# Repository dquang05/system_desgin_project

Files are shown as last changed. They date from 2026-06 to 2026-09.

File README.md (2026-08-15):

# ESP32 Autonomous Mobile Robot (AMR)





An advanced Autonomous Mobile Robot firmware built on the **ESP-IDF v5.x** framework. Designed with strict real-time constraints, thread-safety, and modular architecture, this project demonstrates professional-grade embedded systems engineering using **FreeRTOS** and Object-Oriented C++.

## 🚀 System Architecture

The firmware is designed with a strict **Application-Library Separation**.

- `lib/`: Contains hardware-agnostic, non-blocking drivers (Motor Control, PID, ADC DMA, Loadcell, Wi-Fi). No FreeRTOS tasks are spawned here.
- `src/`: The Application layer orchestrating high-level state machines, task creation, and global resource management.

### Key Engineering Highlights

- **Deterministic Real-Time Execution:** Motion control and PID loops run precisely at 100Hz in a pinned Core 1 task.
- **Thread Safety:** Lock-free passing where possible, combined with strict `portENTER_CRITICAL` Spinlocks for sharing high-frequency data (like Encoder ticks and ADC raw values) across multicore tasks.
- **Zero Dynamic Allocation in Critical Loops:** No `malloc` or `new` in polling loops. Memory is strictly stack-allocated or statically provisioned at startup to prevent Heap Fragmentation.
- **Direct Memory Access (DMA):** The 5-channel Infrared Line Sensor array is sampled at 20kHz continuously via ESP32's ADC DMA hardware, entirely offloading the CPU.

## 🧠 Control Algorithms

### 1. Velocity Control (Low-Level)

- **Incremental PID Controller:** Controls the TB6612 H-Bridge drivers coupled with Quadrature Encoders.
- **Slew Rate Limiting:** Prevents sudden current spikes (Back-EMF) by artificially capping the maximum acceleration `dv/dt`.
- **Integral Anti-Windup:** Prevents overshooting when wheels are mechanically jammed or lose traction.

### 2. Autonomous Navigation (High-Level)

- **Line Tracking:** Uses Weighted Average (Centroid) calculation with Affine Calibration to determine precise offset error (`e2`).
- **State Machine:** Seamlessly transitions between `MOVING_TO_PICKUP`, `WAITING_FOR_PACKAGE` (Loadcell integration), and `DELIVERING`.
- **Two-Phase Pivot Turn:** Executes precise turning maneuvers at intersections without the need for IMU/Compass, relying purely on encoder odometry and side-sensor polling.

### 3. Remote Telemetry & Tuning

- Utilizes asynchronous **UDP Sockets** to broadcast telemetry data (RPM, Duty Cycle, Sensor Arrays) to a local network at high frequency.
- Supports Live-Tuning: Send a JSON payload via UDP to dynamically update PID gains, steering RPMs, or loadcell thresholds **without recompiling or halting the robot**.

## 🛠️ Build & Flash Instructions

This project is configured using standard ESP-IDF CMake.

1. **Prerequisites:** Ensure ESP-IDF v5.x is installed.
2. **Set Target:**
   ```bash
   idf.py set-target esp32
   ```
3. **Build & Flash:**
   ```bash
   idf.py build
   idf.py -p PORT flash monitor
   ```

## 📁 Repository Structure

```text
├── MCU/
│   ├── include/           # Shared structures, Configs, and Orchestrator Headers
│   ├── src/               # FreeRTOS Tasks (Motion, Telemetry, UDP) & Main
│   ├── lib/               # Independent Component Libraries
│   │   ├── adc_dma/       # Continuous DMA ADC Driver
│   │   ├── loadcell_hx711/# HX711 Weight Sensor
│   │   ├── tb6612_encoder/# Motor & Quadrature Encoder Driver
│   │   ├── velocity_pid/  # Slew-Rate Limited PID
│   │   └── wifi_manager/  # Wi-Fi Station & AP provisioning
│   └── CMakeLists.txt     # Global IDF Component Registration
└── UI/                    # Node.js Server & Web Dashboard for UDP Telemetry
```

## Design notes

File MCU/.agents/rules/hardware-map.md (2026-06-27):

---
trigger: model_decision
---

# ESP32-WROOM-32 Hardware Truth (uPesy DevKit)

## 1. RESERVED & HARDWARE-RESTRICTED GPIOs (ABSOLUTE LIMITS)

> **Never assign outputs or remap peripherals to the following GPIOs.**

| GPIO | Category | Hardware Restriction |
|---|---|---|
| **6, 7, 8, 9, 10, 11** | Internal SPI Flash | **DO NOT USE.** These pins are permanently connected to the onboard SPI Flash. Accessing them will cause an immediate Guru Meditation (Crash). |
| **34, 35, 36 (VP), 39 (VN)** | Input Only | **INPUT ONLY.** No output driver and no internal pull-up/pull-down resistors. Never use them for PWM, UART TX, SPI output, or any output function. |

---

## 2. STRAPPING PINS (BOOT CONFIGURATION)

> These GPIOs determine the ESP32 boot mode. External circuitry must never force them into an invalid state during power-up or reset.

| GPIO | Strapping Function | Hardware Constraint |
|---|---|---|
| **0** | Boot Mode | Must be **LOW** to enter download mode. Use caution when connecting buttons or external devices. |
| **2** | Boot Mode & Onboard LED | Must remain in a valid boot state during reset. Commonly connected to the onboard blue LED. |
| **5** | SDIO Timing | Must be **HIGH** during boot. Safe for SPI CS or PWM after boot completes. |
| **12** | Flash Voltage Selection | **CRITICAL.** Must be **LOW** during boot. Driving HIGH selects 1.8V Flash mode and prevents normal boot. |
| **15** | Boot Message Configuration | HIGH enables boot log output, LOW suppresses boot messages. |

---

## 3. DEFAULT PERIPHERAL PIN ASSIGNMENT

> Prefer these default IO-MUX pins unless the hardware design requires GPIO Matrix remapping.

| Peripheral | GPIO Assignment | Notes |
|---|---|---|
| **UART0 (Programming / System Log)** | TX = **1**, RX = **3** | Reserved for USB-UART programming and serial monitor. Avoid using for external peripherals. |
| **UART2** | TX = **17**, RX = **16** | Preferred hardware UART for GPS, LiDAR, and other external modules. |
| **I2C0** | SDA = **21**, SCL = **22** | Default I2C pins. Internal pull-up support available. |
| **VSPI** | MOSI = **23**, MISO = **19**, SCK = **18**, CS = **5** | Preferred SPI bus for maximum compatibility and performance. |

---

## 4. DYNAMIC GPIO MATRIX ALLOCATION

> These assignments depend on the actual hardware design. Always read this table before configuring firmware.

| Function | GPIO | Direction | Notes |
|---|---|---|---|
| **MOTOR_L_PWM** | `[Assign GPIO]` | Output | Use MCPWM or LEDC |
| **MOTOR_R_PWM** | `[Assign GPIO]` | Output | Use MCPWM or LEDC |
| **ENCODER_L_A** | `[Assign GPIO]` | Input | Use PCNT (Pulse Counter) |
| **ENCODER_L_B** | `[Assign GPIO]` | Input | Use PCNT (Pulse Counter) |
| **ENCODER_R_A** | `[Assign GPIO]` | Input | Use PCNT (Pulse Counter) |
| **ENCODER_R_B** | `[Assign GPIO]` | Input | Use PCNT (Pulse Counter) |

---

## 5. ANALOG INPUTS (FIXED ADC CHANNELS)

> Analog sensors must use dedicated ADC GPIOs. Prefer **ADC1** channels to avoid conflicts with Wi-Fi.

| Analog Sensor | GPIO | ADC Channel | Notes |
|---|---|---|---|
| `[Sensor Name]` | `[Assign GPIO]` | `ADC1_CHx` | Prefer ADC1 for Wi-Fi compatibility |

---

## 6. HIGH-SPEED DMA PERIPHERALS (FIXED IO-MUX)

> For high-speed SPI/I2S with DMA, use the native IO-MUX pins below. Do not remap these signals if maximum performance is required.

### VSPI (Up to 80 MHz with DMA)

| Signal | GPIO |
|---|---|
| SCK | **18** |
| MISO | **19** |
| MOSI | **23** |
| CS | **5** |

### HSPI (Up to 80 MHz with DMA)

| Signal | GPIO |
|---|---|
| SCK | **14** |
| MISO | **12** |
| MOSI | **13** |
| CS | **15** |

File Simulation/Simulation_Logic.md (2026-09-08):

# Tài liệu Mô tả Logic Mô phỏng Hệ thống Xe Tự hành (Line Tracking)

Hệ thống mô phỏng một xe tự hành bám đường (line tracking) dựa trên mô hình động học vi sai (differential drive). Quá trình điều khiển được chia làm hai vòng lặp lồng nhau (cascade control): vòng ngoài (Outer Loop) điều hướng xe để bám quỹ đạo dựa trên cảm biến mô phỏng; vòng trong (Inner Loop) điều khiển tốc độ thực tế của từng động cơ trái/phải thông qua các hàm truyền.

Dưới đây là mô tả chi tiết logic và luồng hoạt động của hệ thống, cùng với vai trò của từng file tham gia vào các bước:

## 1. Khởi tạo hệ thống và Sa bàn
**Script chính:** [`main.m`](file:///d:/Projects/system_desgin_project/Simulation/main.m)

- **Thông số cơ học:**
  - Khoảng cách giữa 2 bánh xe (Track width): `b = 246 mm`
  - Khoảng cách từ tâm mảng cảm biến (dò line) đến trục bánh xe: `d = 176 mm`
  - Bán kính bánh xe: `r = 40 mm`
- **Khởi tạo vị trí ban đầu:** 
  - Tâm xe ban đầu tại `(xM, yM) = (0, 0)`, góc lệch `phi = pi`.
  - Tọa độ tâm mảng cảm biến dò line: `xC, yC` được xác định theo tọa độ tâm xe và khoảng cách `d`.
- **Vẽ sa bàn:** Gọi script phụ trợ [`saban.m`](file:///d:/Projects/system_desgin_project/Simulation/saban.m) để phác họa bản đồ môi trường di chuyển với các điểm mốc và giới hạn tọa độ.

---

## 2. Vòng lặp Mô phỏng (Simulation Loop)
Quá trình chạy trong 200 bước (tần số lấy mẫu chung `tsampsys = 0.2s`, khoảng 40 giây thực thi). Tại mỗi chu kỳ, hệ thống thực hiện tuần tự:

### 2.1 Tính toán sai số bám line (Đọc cảm biến)
**Hàm thực thi:** [`get_e2.m`](file:///d:/Projects/system_desgin_project/Simulation/get_e2.m)

- Trạng thái đường đi của xe được chia thành **8 phân đoạn (lines)** dựa trên tọa độ di chuyển dọc trục `xC`.
- **Rẽ nhánh (Phân đoạn 1):** Khi `xC < -2000`, hàm gọi `questdlg` hiển thị popup để chọn lộ trình rẽ: **"Red" (Đỏ)** hoặc **"Blue" (Xanh)**. Biến `color` (1 hoặc 2) lưu trữ lựa chọn sẽ định tuyến cho các phương trình quỹ đạo ở phân đoạn 5, 6, 7 và 8.
- **Tính toán sai số lệch đường (`e`):** Hàm dùng phương trình hình học của đường (thẳng/cong) để chiếu tìm vị trí tâm đường lý tưởng `(xR, yR)`. Từ đó tính toán khoảng cách vuông góc `e` (bằng mm) đại diện cho độ lệch giữa mảng cảm biến xe và trung tâm vạch kẻ lý tưởng.

### 2.2 Bộ điều khiển hướng (Outer Loop PID)
**Hàm thực thi:** [`tracking_line.m`](file:///d:/Projects/system_desgin_project/Simulation/tracking_line.m)

- **Đầu vào:** Sai số vị trí `e` ở chu kỳ hiện tại.
- Bộ điều khiển sử dụng cấu trúc **PID vị trí** (ví dụ: `Kp = 0.045`, `Ki = 0.0`, `Kd = 0.001`) để tính ra tín hiệu điều khiển `w` - vận tốc góc bẻ lái để đưa xe về đúng quỹ đạo.
- Kết hợp với tốc độ chạy tới danh định `vR = 500 mm/s`, bộ điều khiển tổng hợp và trả về **vận tốc góc mục tiêu (RPM)** cho 2 bánh xe trái/phải (`wl`, `wr`).

### 2.3 Mô phỏng điều khiển động cơ (Inner Loop PID)
**Hàm thực thi:** [`pid_motor_left.m`](file:///d:/Projects/system_desgin_project/Simulation/pid_motor_left.m), [`pid_motor_right.m`](file:///d:/Projects/system_desgin_project/Simulation/pid_motor_right.m) và các hàm truyền như [`motor1_tf.m`](file:///d:/Projects/system_desgin_project/Simulation/motor1_tf.m).

Động cơ thực tế có quán tính và độ trễ, do đó phần này được lấy mẫu cao hơn (vòng lặp con với chu kỳ `tsamppid = 0.03s`).
- **PID Tốc độ:** Mỗi động cơ chạy bộ điều khiển PI riêng biệt (ví dụ: `kp1 = 1.0673`, `ki1 = 13.948`) nhằm điều chỉnh sai lệch giữa tốc độ đang chạy và tốc độ yêu cầu (`wl`, `wr`). Đầu ra của PID là giá trị băm xung PWM (`ul`, `ur` trong giới hạn 0-255).
- **Hàm truyền:** Cấp PWM vào hàm truyền bậc 1 của động cơ (`K = 12.05`, `a = 10.64`).
- Hệ thống giải phương trình vi phân liên tục qua lệnh `ode45` trong MATLAB để tìm ra **vận tốc tịnh tiến thực tế** `vl`, `vr` (mm/s) đáp ứng ra tại bánh xe.

### 2.4 Cập nhật động học hệ thống (Kinematics)
**Hàm thực thi:** [`dynamic_tf.m`](file:///d:/Projects/system_desgin_project/Simulation/dynamic_tf.m) tích hợp trong `main.m`.

- Từ vận tốc thực tế của hai bánh `vl`, `vr`, xác định vận tốc tịnh tiến hệ thống: $v_{input} = \frac{vl + vr}{2}$ và vận tốc xoay thân xe $w_{input} = \frac{vr - vl}{b}$.
- Đưa qua phương trình vi phân động học robot vi sai:
  - $\dot{x} = v \cos(\phi)$
  - $\dot{y} = v \sin(\phi)$
  - $\dot{\phi} = w$
- Giải qua `ode45` để tìm ra tọa độ không gian mới `(xM, yM)` và góc hướng mũi xe `phi`. Cập nhật tịnh tiến mảng cảm biến `(xC, yC)` lên phía trước.
- Xóa frame cũ và vẽ đè hình ảnh xe mới bằng các hàm `plot` và lệnh `drawnow`, sinh ra hoạt ảnh xe di chuyển mượt mà trên môi trường giả lập.

---

## 3. Phân tích Đáp ứng Động cơ (Hỗ trợ)
**Script phụ trợ:** [`motor_response.m`](file:///d:/Projects/system_desgin_project/Simulation/motor_response.m)

- Đóng vai trò là kịch bản mô phỏng tĩnh để đánh giá thiết kế vòng điều khiển vận tốc.
- Sinh đồ thị hàm Step (Step Response) cho vòng kín chứa Động cơ + Bộ PID vận tốc.
- Phân tích và trích xuất các chỉ số chất lượng: **Overshoot** (Độ vọt lố), **Settling Time** (Thời gian xác lập), và **Steady-State Error** (Sai số xác lập) lưu vào tập tin báo cáo `motor_simulation_results.txt`.

---

## 4. Tổng hợp Kết quả và Báo cáo (Kết thúc mô phỏng)
Sau 200 chu kỳ chạy, cuối file `main.m` thực hiện lưu vết và phân tích:
1. **Biểu đồ trực quan:**
   - Đồ thị sai số cảm biến dò line theo thời gian (quan sát độ lặp, lắc thân xe).
   - Đồ thị tốc độ góc mong muốn của 2 bánh xe (RPM).
   - Đồ thị tốc độ dài thực tế của động cơ sau xử lý độ trễ (mm/s).
2. **Xuất báo cáo văn bản:** Trích xuất kết quả ra tệp [`main_simulation_results.txt`](file:///d:/Projects/system_desgin_project/Simulation/main_simulation_results.txt) gồm:
   - Sai số hiệu dụng (RMS Error) và sai số tích phân (IAE).
   - Số lần cắt ngang tâm đường (Zero-crossings) cảnh báo xe bị lắc.
   - Vị trí và khoảng thời gian xe bị overshoot lệch khỏi quỹ đạo xa nhất.

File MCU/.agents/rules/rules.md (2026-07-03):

---
trigger: glob
globs: src/**/*.{c,cpp,h}, include/**/*.h, lib/**/*.{c,cpp,h}, **/CMakeLists.txt
---

Role: ESP32 Firmware Engineer (PlatformIO & ESP-IDF v5.4)

# Architecture & Build Rules

- Framework: ESP-IDF v5.4 ONLY (No Arduino). Structure: `src/`, `include/`, `lib/`.
- Build: Always update `CMakeLists.txt` (`idf_component_register`) when adding `.c/.cpp/.h/.hpp`. Never edit `sdkconfig` directly.
- API: Strictly use v5.x drivers (e.g., `mcpwm_prelude.h`). Zero v4.x legacy APIs.

# Coding Style & Library Design

- Naming: `snake_case` (files, methods, vars), `PascalCase` (classes), `UPPER_SNAKE_CASE` (macros). Private vars prefix: `_`.
- Decoupling [CRITICAL]: NO hardcoded pins/magic numbers in `lib/`. Pass via config structs, macros, or `constexpr` in headers.
- Task Architecture [CRITICAL]: NEVER create FreeRTOS tasks inside `lib/`. Libraries must expose non-blocking methods (`process()`, `poll()`). Task creation belongs strictly to the App layer (`main`).
- Syntax [CRITICAL]: C++17 or C++20.

# Memory & Resource Management

- Allocation: NO dynamic allocation (`malloc`, `new`, `std::vector`, `std::string`) in continuous loops or ISRs. Use static/stack memory (`std::array`, C-arrays). If required, allocate exactly once at `init()`. Prefer static FreeRTOS objects.
- Safety: Always bounds-check arrays, NULL-check pointers, race-condition check. Full cleanup on deinit (disable modules, reset GPIOs, free ISRs).

# Hardware, Clock & Peripherals

- Clocks: Use `esp_clk_apb_freq()` (Never hardcode 80MHz). Validate clock configs. Wrap all inits in `ESP_ERROR_CHECK()`. Always call `periph_module_enable()` before register access.
- SPI & GPIO: SPI FIFO > 64B MUST be chunked. Route pins via `gpio_matrix_out/in()`.
- Concurrency: Protect ISR/Task shared memory using spinlocks (`portENTER_CRITICAL`).

# FreeRTOS & Safety Checks

- Execution: Every polling loop MUST have a time-based timeout (`esp_timer_get_time()`). No infinite loops.
- WDT: DO NOT bypass WDT with `esp_task_wdt_reset()`; fix CPU starvation instead. Always yield CPU (`vTaskDelay`, `taskYIELD()`) in heavy loops.

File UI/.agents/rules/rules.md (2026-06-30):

---
trigger: always_on
---

# UI Project Agent Rules

## Tech Stack

- Backend: Node.js, Express.js, Socket.io, `dgram` (UDP server).
- Frontend: Vanilla HTML, CSS, JavaScript. No frontend frameworks.
- Backend receives UDP datagrams from the MCU and forwards them to the frontend via WebSockets.

## Backend

- Keep the UDP-to-WebSocket bridge architecture.
- Implement UDP socket self-recovery on errors using automatic restart (e.g., `setTimeout`).
- Clean up all sockets and timers on `SIGINT` and `SIGTERM`.

## Frontend

- Use only native DOM APIs.
- Batch high-frequency updates with `requestAnimationFrame` and `DocumentFragment`.
- Limit log elements with a FIFO queue (maximum 1000).
- Sanitize all incoming data before inserting it into the DOM.
- Preserve the dark theme using `--bg-color`, `--panel-bg`, and `--accent`.
- Provide real-time status indicators and controls (auto-scroll, clear logs).
- Automatically parse and syntax-highlight JSON payloads in logs.

```

```

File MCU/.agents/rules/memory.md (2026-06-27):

---
trigger: always_on
glob:
description:
---

# ESP32 ADC DMA & FreeRTOS Lessons Learned

- **ADC Calibration**: ESP32 (classic) only supports `Line Fitting` calibration (`adc_cali_create_scheme_line_fitting`). Using `Curve Fitting` will fail as it is disabled in `adc_cali_scheme.h` for this chip.
- **ESP-IDF v5 Spinlock Initialization**: Avoid using internal macros like `vPortCPUInitializeMutex` in modern ESP-IDF v5.x to initialize a Spinlock (`portMUX_TYPE`). Instead, initialize it directly using the macro `portMUX_INITIALIZER_UNLOCKED` (e.g., `portMUX_TYPE _spinlock = portMUX_INITIALIZER_UNLOCKED;`).
- **ADC DMA Zero Queue Architecture**: To minimize overhead and avoid FreeRTOS RingBuffer or xQueue complexities, parse the ADC continuous DMA buffer locally on the stack and safely copy the latest complete frame to a shared struct protected by a Spinlock (`portENTER_CRITICAL` / `portEXIT_CRITICAL`). This prevents race conditions with minimal latency.
- **ADC Continuous Read Timeout**: The `timeout_ms` parameter in `adc_continuous_read()` expects raw milliseconds, NOT FreeRTOS ticks. Passing `pdMS_TO_TICKS(10)` evaluates to ~1ms (or 0), causing an immediate timeout and potential Task Watchdog (TWDT) crash due to a tight spinning loop.
- **Task Watchdog & Yielding**: When an infinite loop task polls for data (e.g., getting `ESP_ERR_TIMEOUT`), it MUST explicitly yield the CPU (e.g., using `vTaskDelay(pdMS_TO_TICKS(10))`) to prevent TWDT CPU starvation.
- **PlatformIO ESP-IDF Component Registration**: Any custom library placed in the `lib/` directory MUST have a `CMakeLists.txt` file calling `idf_component_register()` to be compiled and have its include paths exported properly to the rest of the project.

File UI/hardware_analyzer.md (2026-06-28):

# Hardware Analysis

Dựa trên mã nguồn C/C++ trong thư mục `hardware_code/`, các thông số mạng được trích xuất như sau:

- **Protocol**: UDP (`SOCK_DGRAM`)
  - Tìm thấy tại `wifi_manager.cpp`, dòng 184: `int sock = socket(AF_INET, SOCK_DGRAM, IPPROTO_IP);`
- **Port**: `8080`
  - Tìm thấy tại `WifiTest.cpp`, dòng 59: `wifi.send_log_data("192.168.1.100", 8080, ...)`

Server backend sẽ được thiết lập để lắng nghe UDP Datagram trên cổng `8080`.

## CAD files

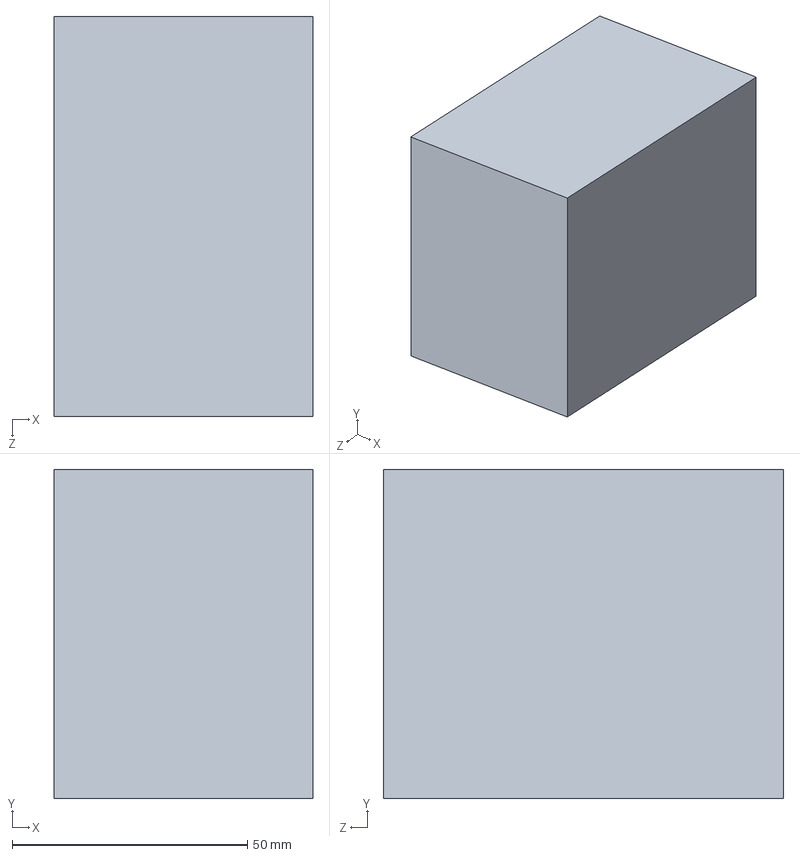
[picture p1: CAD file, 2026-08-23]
3D_Model/Tai_mau_do.SLDPRT
55.0 x 70.0 x 85.0 mm

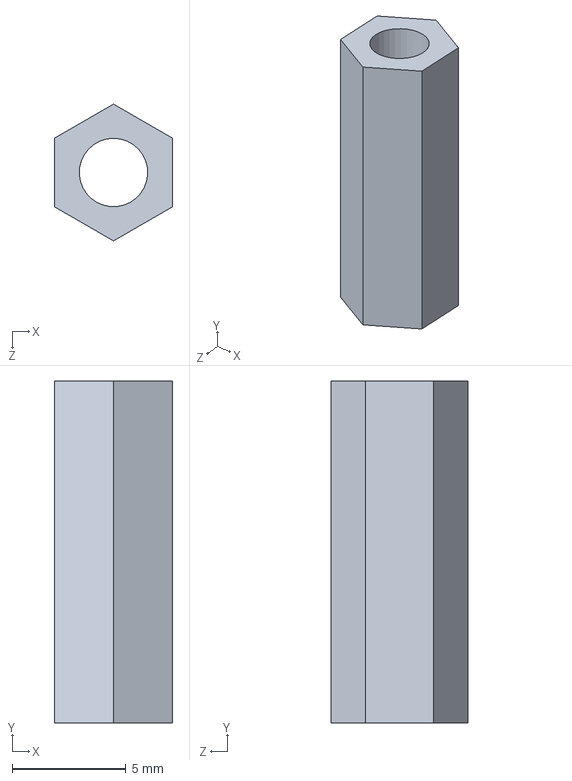
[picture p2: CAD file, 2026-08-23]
3D_Model/cot chong15.SLDPRT
5.20 x 15.0 x 6.00 mm

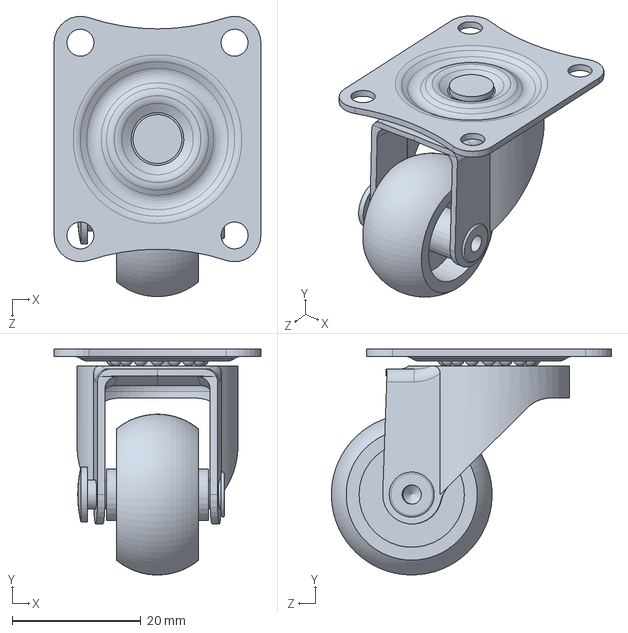
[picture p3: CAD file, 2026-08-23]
3D_Model/Caster_Wheel.SLDPRT
32.2 x 35.1 x 43.5 mm

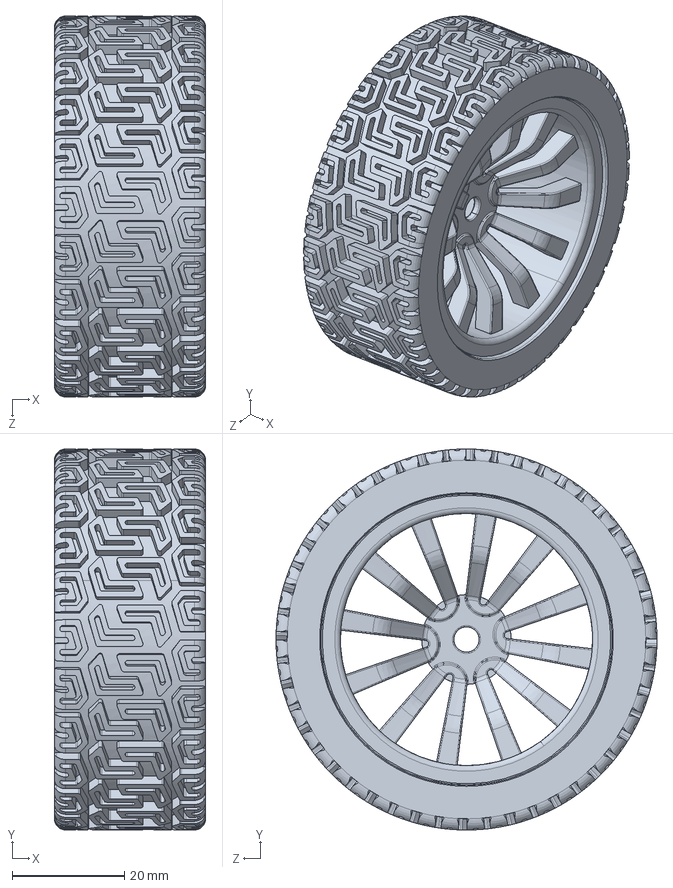
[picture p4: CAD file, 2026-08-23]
3D_Model/Banh_V2_65mm.SLDPRT
27.0 x 68.0 x 68.0 mm

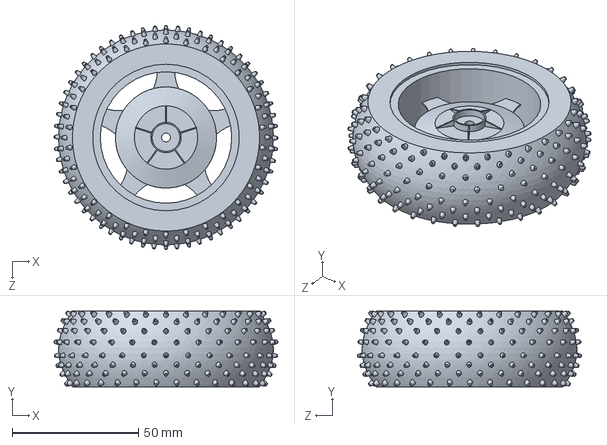
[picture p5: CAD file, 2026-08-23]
3D_Model/85mm_Wheel.SLDPRT
88.6 x 30.0 x 88.7 mm

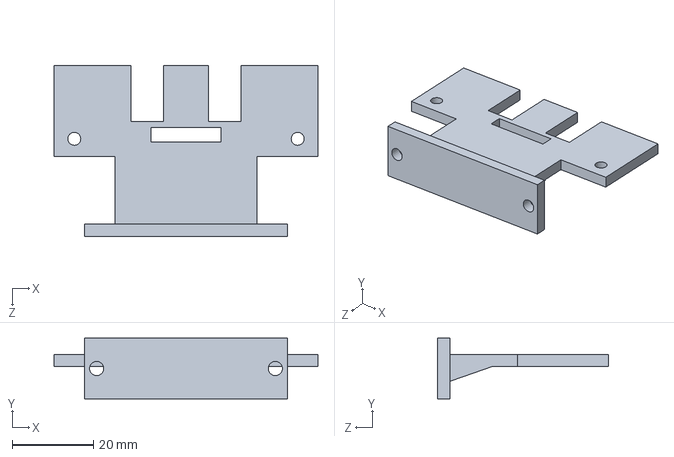
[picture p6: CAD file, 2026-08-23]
3D_Model/Ga_cam_bien_mau.SLDPRT
65.0 x 15.0 x 42.0 mm

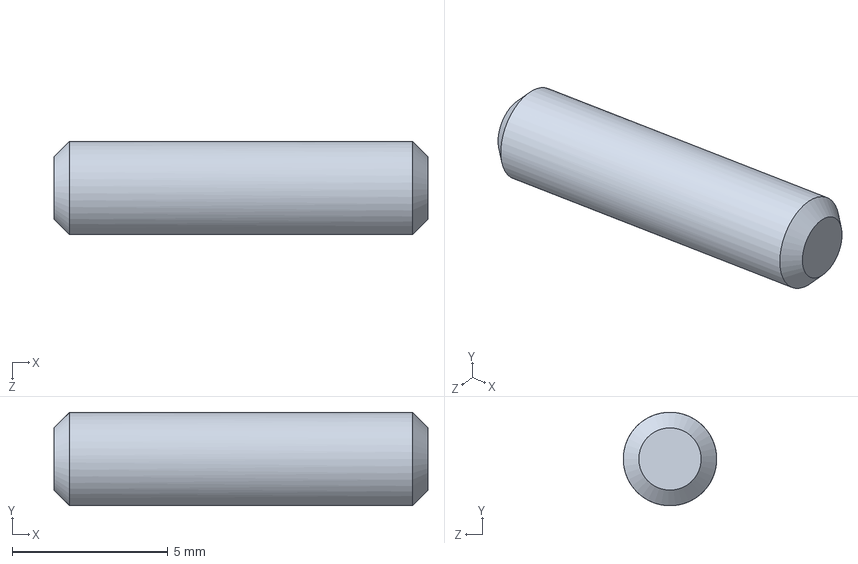
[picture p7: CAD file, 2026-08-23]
3D_Model/Chot_dinh_vi.SLDPRT
12.0 x 3.00 x 3.00 mm

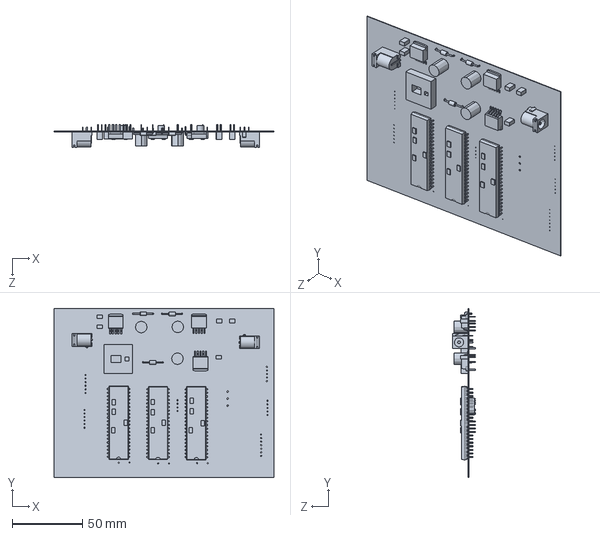
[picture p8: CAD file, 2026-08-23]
3D_Model/PCB.SLDPRT
156.6 x 120.5 x 16.0 mm

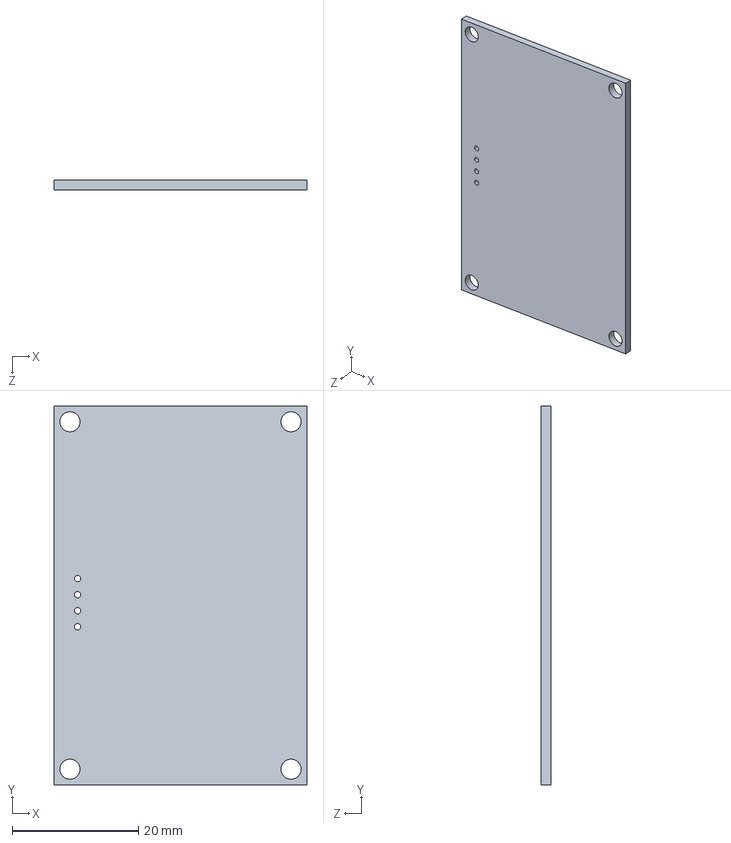
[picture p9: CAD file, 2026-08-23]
3D_Model/board_4x6.SLDPRT
40.0 x 60.0 x 1.51 mm

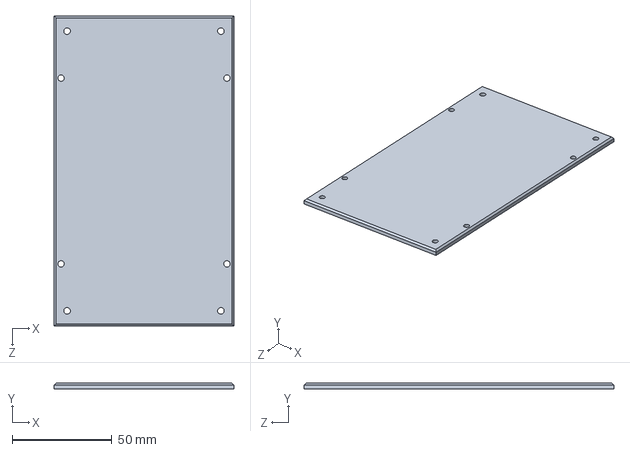
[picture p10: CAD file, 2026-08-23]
3D_Model/Part1.SLDPRT
90.0 x 3.00 x 155.2 mm

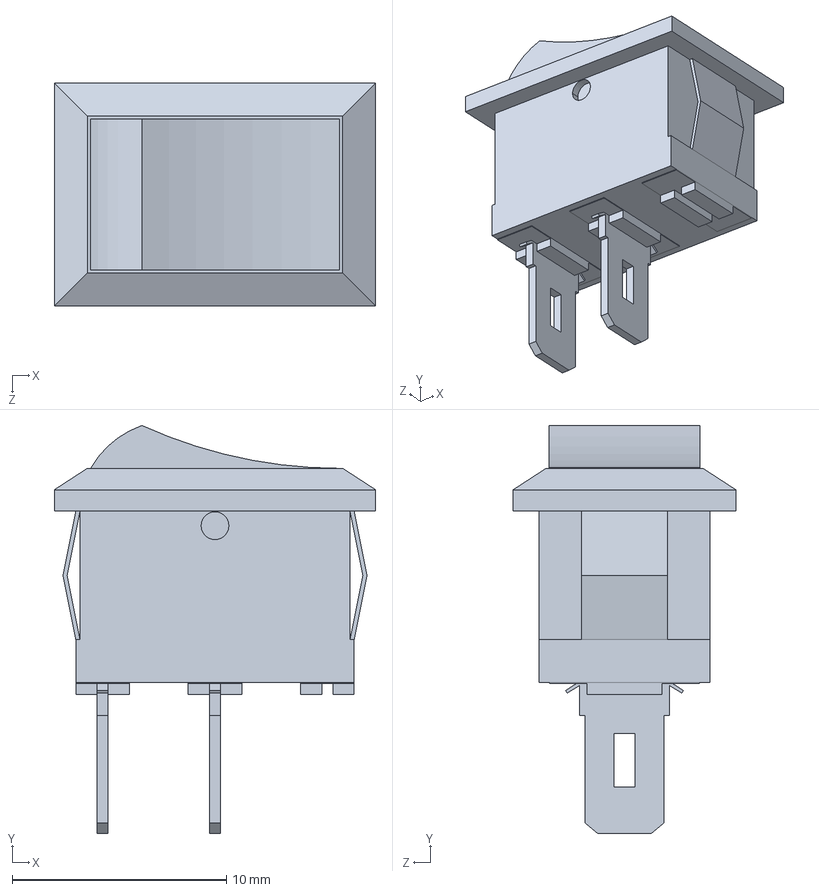
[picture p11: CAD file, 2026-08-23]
3D_Model/SwitchOnOff.SLDPRT
15.0 x 19.1 x 10.4 mm

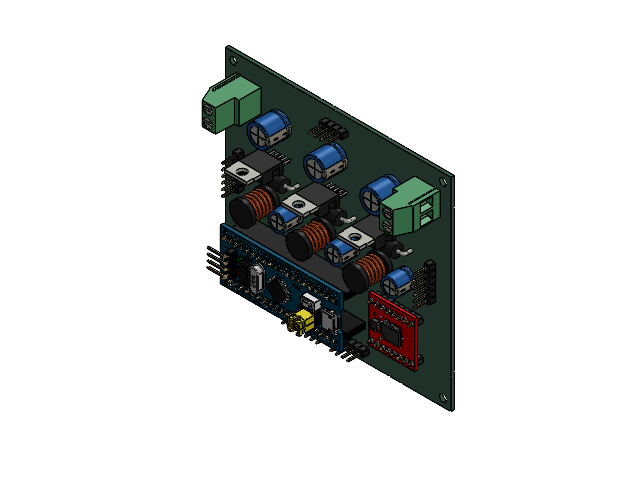
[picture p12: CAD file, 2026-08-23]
3D_Model/Electrical_Board.SLDASM
CP_Radial_D8.0mm_P3.50mm.step x 3
PinHeader_1x04_P2.54mm_Vertical.step x 2
TO-220-5_Vertical.step x 3
TerminalBlock_Phoenix_MKDS-3-2-5.08_1x02_P5.08mm_Horizontal.step x 2
PinHeader_1x06_P2.54mm_Vertical.step x 2
D_DO-201AD_P15.24mm_Horizontal.step x 3
CP_Radial_D10.0mm_P5.00mm.step x 3
L_Radial_D10.0mm_P5.00mm_Fastron_07P.step x 3
PinHeader_1x07_P2.54mm_Vertical.step
YAAJ_BluePill_PinSockets_H_SWD_cp.step
ROB-14450.step
Electrical_Board_PCB.step

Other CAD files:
3D_Model/MirrorBanh_xe_64mm_phi6_E3600293.SLDPRT
3D_Model/MirrorGa_dong_co.SLDPRT
3D_Model/MirrorBanh_V2_65mm.SLDPRT
3D_Model/MirrorTruc_dong_co.SLDPRT
3D_Model/MirrorNoi_truc.SLDPRT
3D_Model/MirrorKhay_pin.SLDPRT
3D_Model/4x6_Board_new.SLDPRT
3D_Model/Cam_bien_GY-33 TCS34725.SLDPRT
3D_Model/Dong_co_DC_JGB37-520.SLDPRT
3D_Model/Ga_banh_caster_2.SLDPRT
3D_Model/Ga_banh_caxter.SLDPRT
3D_Model/Ga_dong_co.SLDPRT
3D_Model/Ga_dong_co_2.SLDPRT
3D_Model/Hop_che_cam_bien.SLDPRT
3D_Model/Khay_dung_hang.SLDPRT
3D_Model/Khay_pin.SLDPRT
3D_Model/Khung_xe.SLDPRT
3D_Model/LineSensor_Board.SLDPRT
3D_Model/LineSensor_Board_1.SLDPRT
3D_Model/MirrorDong_co_DC_JGB37-520.SLDPRT
3D_Model/Noi_truc.SLDPRT
3D_Model/PCB_F.SLDPRT
3D_Model/Tam dung mach in.SLDPRT
3D_Model/Truc_dong_co.SLDPRT
3D_Model/cot chong50.SLDPRT

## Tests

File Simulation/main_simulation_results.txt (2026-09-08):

=== BÁO CÁO MÔ PHỎNG MAIN.M ===
1. Đánh giá tổng quan (Độ bám):
- Thời gian mô phỏng: 12.80 s
- RMS Error (Sai số hiệu dụng): 11.9327 mm
- IAE (Tổng sai số cộng dồn): 98.7142

2. Đánh giá Dao động (Lắc đuôi):
- Số lần quét qua tâm vạch (Zero-crossings): 20 lần
  -> [CẢNH BÁO]: Xe bị dao động zigzag. AI Agent nên gợi ý giảm Kp hoặc tăng Kd ở hàm tracking_line!

3. Đánh giá Văng cua (Overshoot):
- Lỗi văng xa nhất: 23.2498 mm
- Thời điểm xảy ra lỗi lớn nhất: t = 5.60 s

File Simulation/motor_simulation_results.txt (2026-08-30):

=== BÁO CÁO MÔ PHỎNG MOTOR_RESPONSE.M ===
Target Speed: 100.00

--- Động cơ 1 (Bánh Trái) ---
Hàm truyền: K1 = 12.0500, a1 = 10.6400
PID       : Kp1 = 1.0673, Ki1 = 13.9480, Kd1 = 0.0000
Đáp ứng   : Overshoot = 0.89 %, Settling Time = 0.2085 s, SSE = 0.0000

--- Động cơ 2 (Bánh Phải) ---
Hàm truyền: K2 = 9.8660, a2 = 8.9220
PID       : Kp2 = 1.2452, Ki2 = 13.6563, Kd2 = 0.0000
Đáp ứng   : Overshoot = 1.07 %, Settling Time = 0.2192 s, SSE = 0.0000

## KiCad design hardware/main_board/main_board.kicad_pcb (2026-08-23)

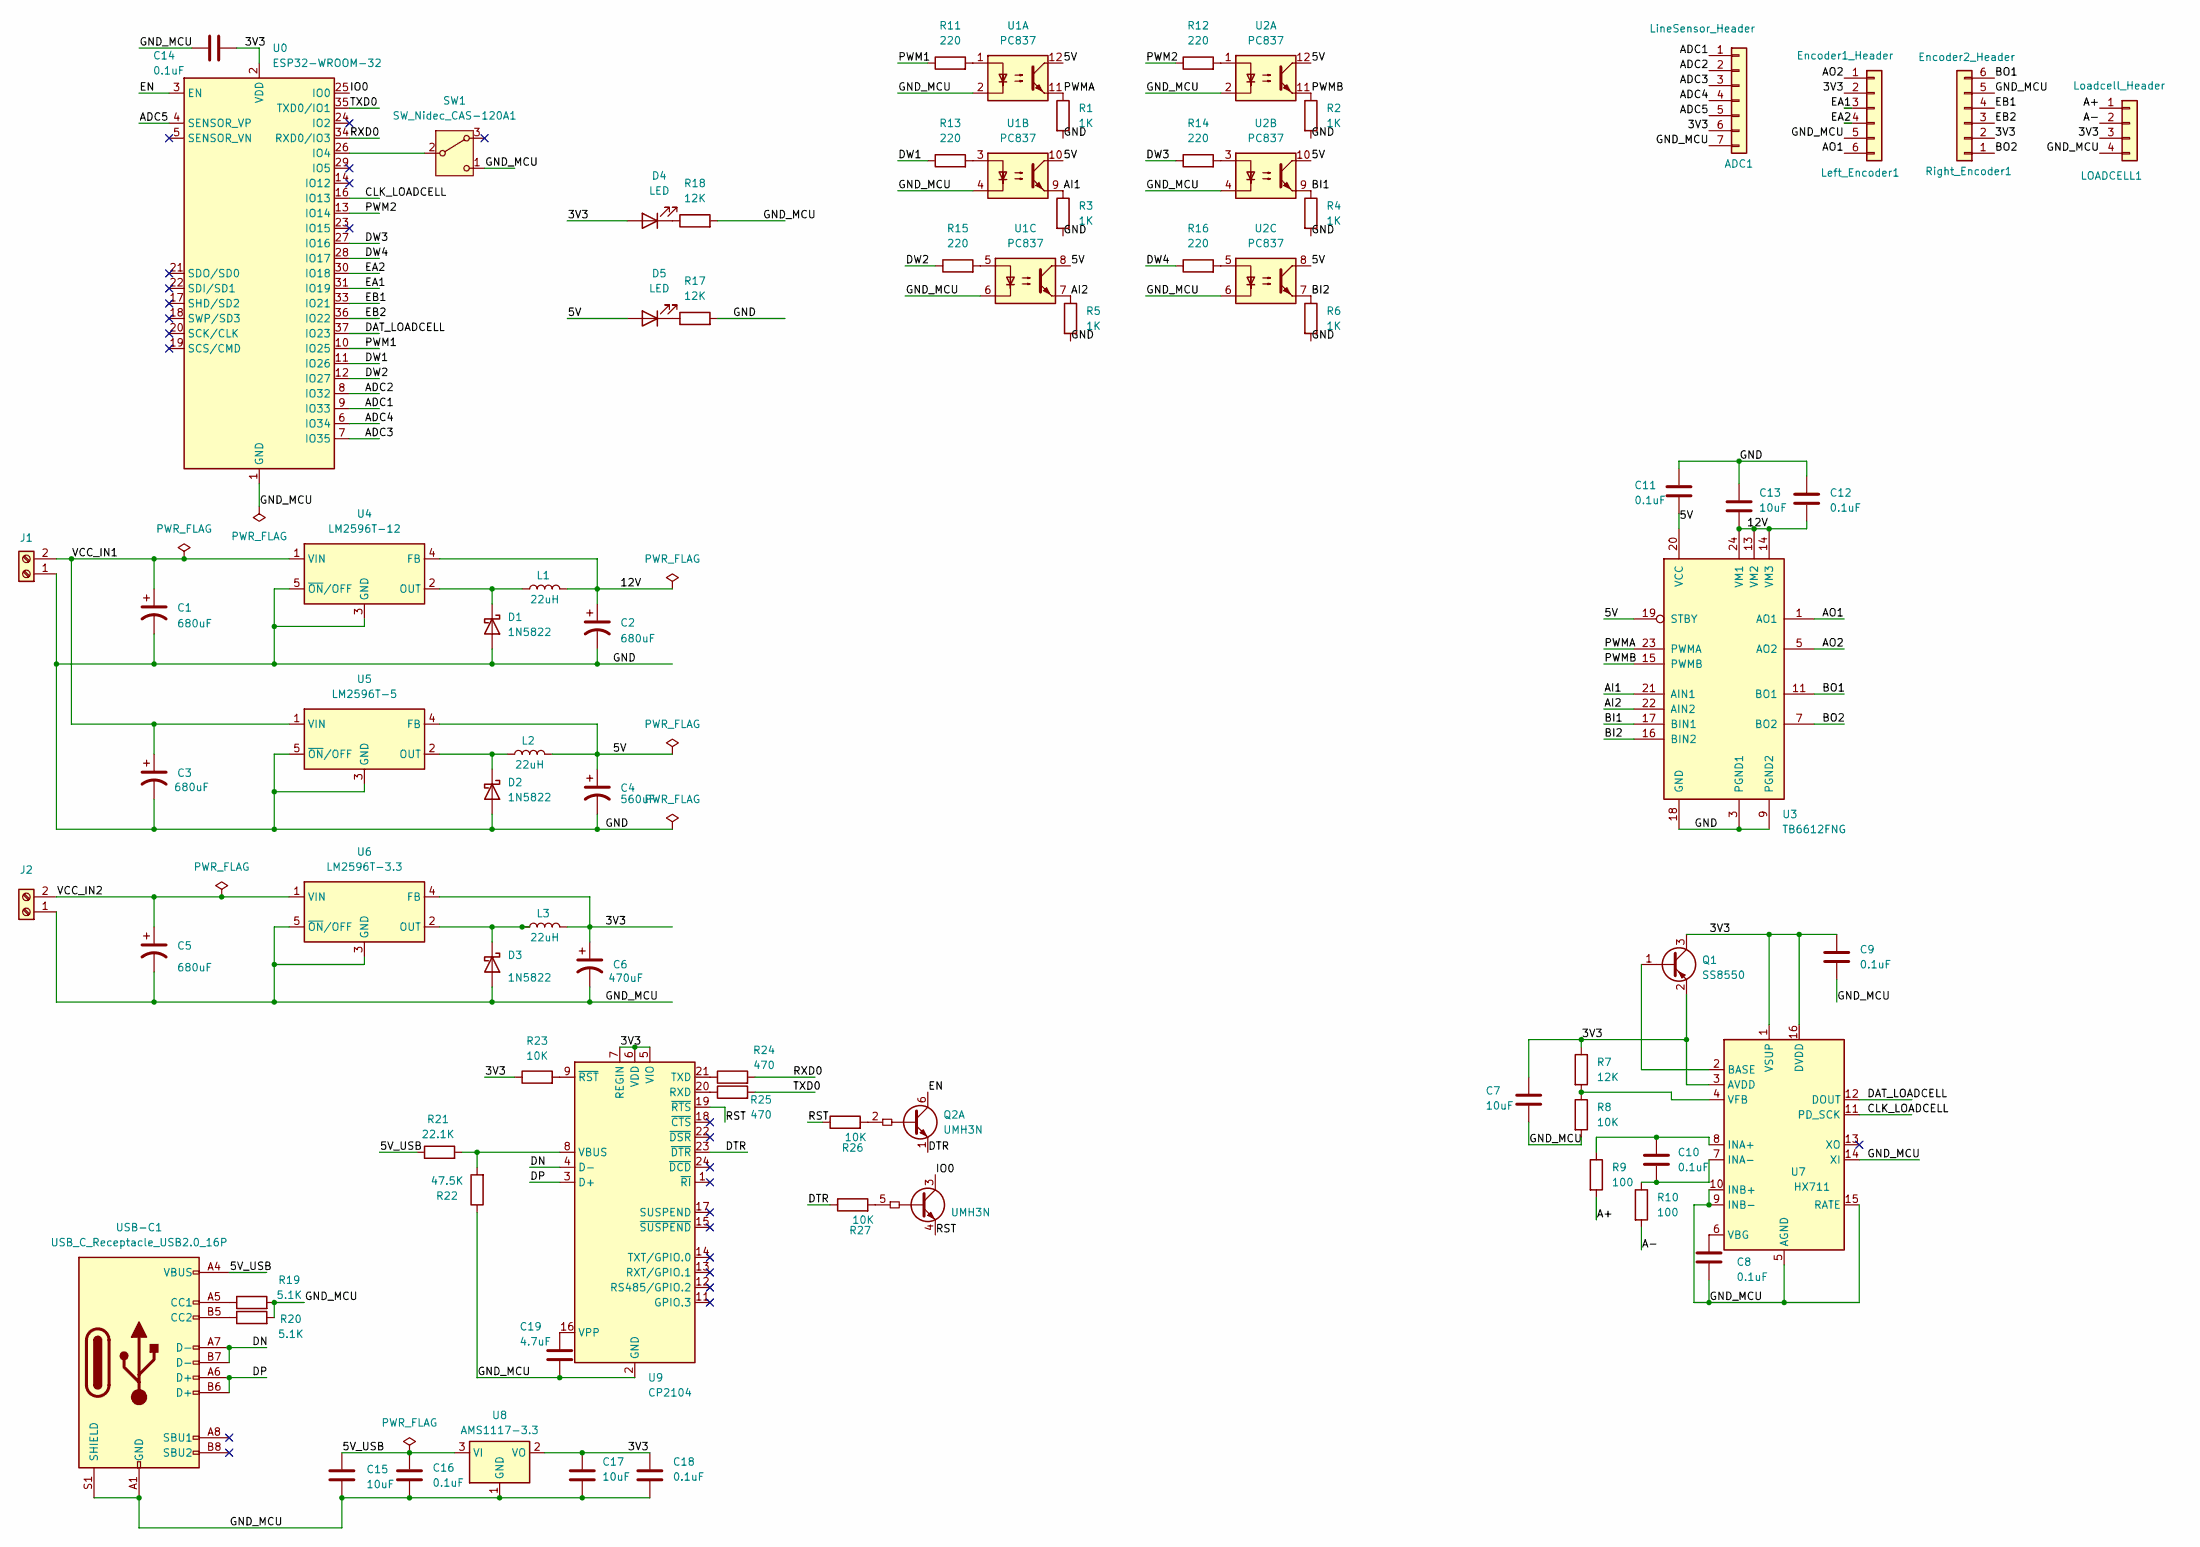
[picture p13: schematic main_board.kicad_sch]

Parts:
ADC1: LineSensor_Header; JST_EH_S7B-EH_1x07_P2.50mm_Horizontal
C1, C2, C3, C5: 680uF; CP_Radial_D8.0mm_P5.00mm
C4: 560uF; CP_Radial_D8.0mm_P5.00mm
C6: 470uF; CP_Radial_D8.0mm_P5.00mm
C7, C15, C17: 10uF; C_0805_2012Metric
C8, C9, C10, C11, C12, C14, C16, C18: 0.1uF; C_0805_2012Metric
C13: 10uF; C_1812_4532Metric_Pad1.57x3.40mm_HandSolder
C19: 4.7uF; C_0805_2012Metric
D1, D2, D3: 1N5822; D_0805_2012Metric
D4, D5: LED; LED_0805_2012Metric
J1: MCU POWER; TerminalBlock_bornier-2_P5.08mm
J2: MOTOR POWER; TerminalBlock_bornier-2_P5.08mm
L1, L2, L3: 22uH; L_6.3x6.3_H3
LOADCELL1: Loadcell_Header; JST_EH_S4B-EH_1x04_P2.50mm_Horizontal
Left_Encoder1: Encoder1_Header; JST_EH_S6B-EH_1x06_P2.50mm_Horizontal
Q1: SS8550; SOT-23
Q2: UMH3N; SOT-363_SC-70-6
R1, R2, R3, R4, R5, R6: 1K; R_0603_1608Metric
R7, R17, R18: 12K; R_0603_1608Metric
R8, R23, R26, R27: 10K; R_0603_1608Metric
R9, R10: 100; R_0603_1608Metric
R11, R12, R13, R14, R15, R16: 220; R_0603_1608Metric
R19, R20: 5.1K; R_0603_1608Metric
R21: 22.1K; R_0603_1608Metric
R22: 47.5K; R_0603_1608Metric
R24, R25: 470; R_0603_1608Metric
Right_Encoder1: Encoder2_Header; JST_EH_S6B-EH_1x06_P2.50mm_Horizontal
SW1: SW_Nidec_CAS-120A1; SW_DIP_SPSTx01_Slide_6.7x4.1mm_W6.73mm_P2.54mm_LowProfile_J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
U0: ESP32-WROOM-32
U1, U2: PC837; DIP-12_W7.62mm
U3: TB6612FNG; SSOP-24_5.3x8.2mm_P0.65mm
U4: LM2596T-12; TO-220-5_Vertical
U5: LM2596T-5; TO-220-5_Vertical
U6: LM2596T-3.3; TO-220-5_Vertical
U7: HX711; SOIC-16_3.9x9.9mm_P1.27mm
U8: AMS1117-3.3; SOT-223-3_TabPin2
U9: CP2104; QFN-24-1EP_4x4mm_P0.5mm_EP2.6x2.6mm
USB-C1: USB_C_Receptacle_USB2.0_16P; USB_C_Receptacle_GCT_USB4105-xx-A_16P_TopMnt_Horizontal

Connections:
/3V3: ADC1.6, C6.1, C7.1, C9.1, C14.1, C17.1, C18.1, D4.2 (A), L3.2, LOADCELL1.3, Left_Encoder1.2, Q1.2 (E), Q1.3 (C), R7.1, R23.1, Right_Encoder1.2, U0.2 (VDD), U6.4 (FB), U7.1 (VSUP), U7.3 (AVDD), U7.16 (DVDD), U8.2 (VO), U9.5 (VIO), U9.6 (VDD), U9.7 (REGIN)
/5V: C4.1, C11.2, D5.2 (A), L2.2, U1.8, U1.10, U1.12, U2.8, U2.10, U2.12, U3.19 (STBY), U3.20 (VCC), U5.4 (FB)
/5V_USB: C15.1, C16.1, R21.1, U8.3 (VI), USB-C1.A4 (VBUS), USB-C1.A9 (VBUS), USB-C1.B4 (VBUS), USB-C1.B9 (VBUS)
/12V: C2.1, C12.2, C13.2, L1.2, U3.13 (VM2), U3.14 (VM3), U3.24 (VM1), U4.4 (FB)
/A+: LOADCELL1.1, R9.2
/A-: LOADCELL1.2, R10.2
/ADC1: ADC1.1, U0.9 (IO33)
/ADC2: ADC1.2, U0.8 (IO32)
/ADC3: ADC1.3, U0.7 (IO35)
/ADC4: ADC1.4, U0.6 (IO34)
/ADC5: ADC1.5, U0.4 (SENSOR_VP)
/AI1: R3.1, U1.9, U3.21 (AIN1)
/AI2: R5.1, U1.7, U3.22 (AIN2)
/AO1: Left_Encoder1.6, U3.1 (AO1), U3.2 (AO1)
/AO2: Left_Encoder1.1, U3.5 (AO2), U3.6 (AO2)
/BI1: R4.1, U2.9, U3.17 (BIN1)
/BI2: R6.1, U2.7, U3.16 (BIN2)
/BO1: Right_Encoder1.6, U3.11 (BO1), U3.12 (BO1)
/BO2: Right_Encoder1.1, U3.7 (BO2), U3.8 (BO2)
/CLK_LOADCELL: U0.16 (IO13), U7.11 (PD_SCK)
/DAT_LOADCELL: U0.37 (IO23), U7.12 (DOUT)
/DN: U9.4 (D-), USB-C1.A7 (D-), USB-C1.B7 (D-)
/DP: U9.3 (D+), USB-C1.A6 (D+), USB-C1.B6 (D+)
/DTR: Q2.1 (E1), R27.1, U9.23 (~DTR)
/DW1: R13.1, U0.11 (IO26)
/DW2: R15.1, U0.12 (IO27)
/DW3: R14.1, U0.27 (IO16)
/DW4: R16.1, U0.28 (IO17)
/EA1: Left_Encoder1.3, U0.31 (IO19)
/EA2: Left_Encoder1.4, U0.30 (IO18)
/EB1: Right_Encoder1.4, U0.33 (IO21)
/EB2: Right_Encoder1.3, U0.36 (IO22)
/EN: Q2.6 (C1), U0.3 (EN)
/GND: C1.2, C2.2, C3.2, C4.2, C11.1, C12.1, C13.1, D1.2 (A), D2.2 (A), J1.1, R1.2, R2.2, R3.2, R4.2, R5.2, R6.2, R17.2, U3.3 (PGND1), U3.4 (PGND1), U3.9 (PGND2), U3.10 (PGND2), U3.18 (GND), U4.3 (GND), U4.5 (~ON/OFF), U5.3 (GND), U5.5 (~ON/OFF)
/GND_MCU: ADC1.7, C5.2, C6.2, C7.2, C8.2, C9.2, C14.2, C15.2, C16.2, C17.2, C18.2, C19.2, D3.2 (A), J2.1, LOADCELL1.4, Left_Encoder1.5, R8.2, R18.2, R19.2, R20.2, R22.1, Right_Encoder1.5, SW1.1 (C), U0.1 (GND), U0.15 (GND), U0.38 (GND), U0.39 (GND), U1.2, U1.4, U1.6, U2.2, U2.4, U2.6, U6.3 (GND), U6.5 (~ON/OFF), U7.5 (AGND), U7.9 (INB-), U7.10 (INB+), U7.14 (XI), U7.15 (RATE), U8.1 (GND), U9.2 (GND), U9.25 (GND), USB-C1.A1 (GND), USB-C1.A12 (GND), USB-C1.B1 (GND), USB-C1.B12 (GND), USB-C1.S1 (SHIELD)
/IO0: Q2.3 (C2), U0.25 (IO0)
/PWM1: R11.1, U0.10 (IO25)
/PWM2: R12.1, U0.13 (IO14)
/PWMA: R1.1, U1.11, U3.23 (PWMA)
/PWMB: R2.1, U2.11, U3.15 (PWMB)
/RST: Q2.4 (E2), R26.1, U9.19 (~RTS)
/RXD0: R24.2, U0.34 (RXD0/IO3)
/TXD0: R25.2, U0.35 (TXD0/IO1)
/VCC_IN1: C1.1, C3.1, J1.2, U4.1 (VIN), U5.1 (VIN)
/VCC_IN2: C5.1, J2.2, U6.1 (VIN)
unnamed: D1.1 (K), L1.1, U4.2 (OUT)
unnamed: D2.1 (K), L2.1, U5.2 (OUT)
unnamed: D3.1 (K), L3.1, U6.2 (OUT)
unnamed: D4.1 (K), R18.1
unnamed: D5.1 (K), R17.1
unnamed: Q1.1 (B), U7.2 (BASE)
unnamed: Q2.2 (B1), R26.2
unnamed: Q2.5 (B2), R27.2
unnamed: R11.2, U1.1
unnamed: R12.2, U2.1
unnamed: R13.2, U1.3
unnamed: R14.2, U2.3
unnamed: R15.2, U1.5
unnamed: R16.2, U2.5
unnamed: SW1.2 (B), U0.26 (IO4)
unnamed: C10.1, R9.1, U7.8 (INA+)
unnamed: C10.2, R10.1, U7.7 (INA-)
unnamed: C8.1, U7.6 (VBG)
unnamed: R7.2, R8.1, U7.4 (VFB)
unnamed: R25.1, U9.20 (RXD)
unnamed: R24.1, U9.21 (TXD)
unnamed: R21.2, R22.2, U9.8 (VBUS)
unnamed: C19.1, U9.16 (VPP)
unnamed: R23.2, U9.9 (~RST)
unnamed: R19.1, USB-C1.A5 (CC1)
unnamed: R20.1, USB-C1.B5 (CC2)

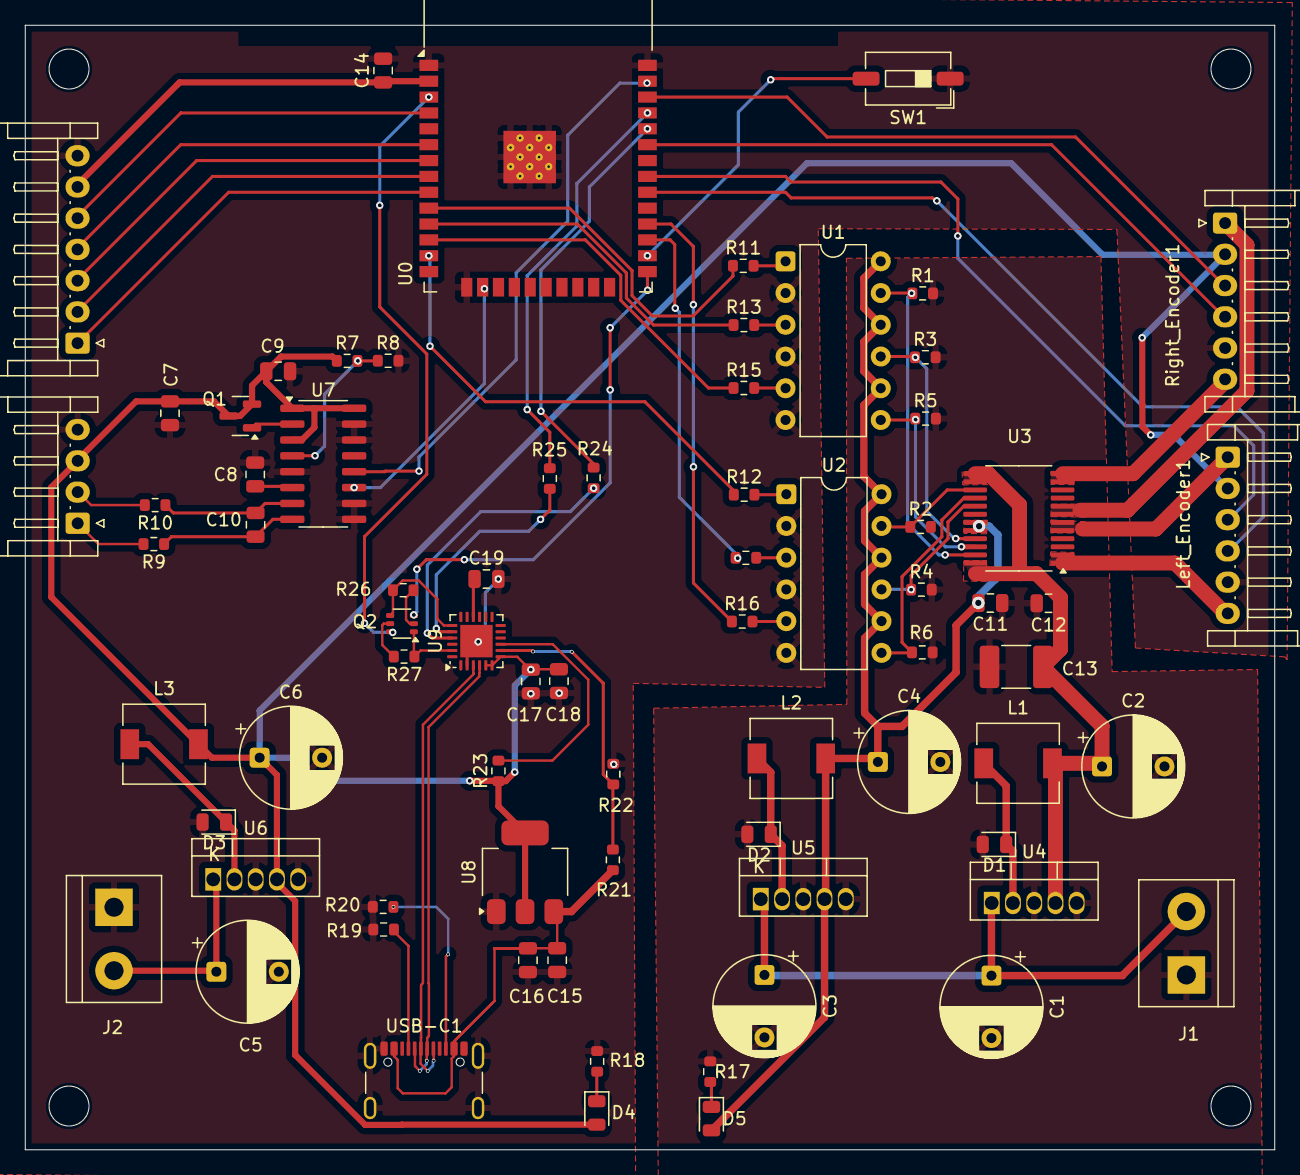
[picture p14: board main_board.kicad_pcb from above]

Board: 2 copper layers, 100.0 x 90.0 mm, 74 parts (0 on the bottom side), 71 nets.

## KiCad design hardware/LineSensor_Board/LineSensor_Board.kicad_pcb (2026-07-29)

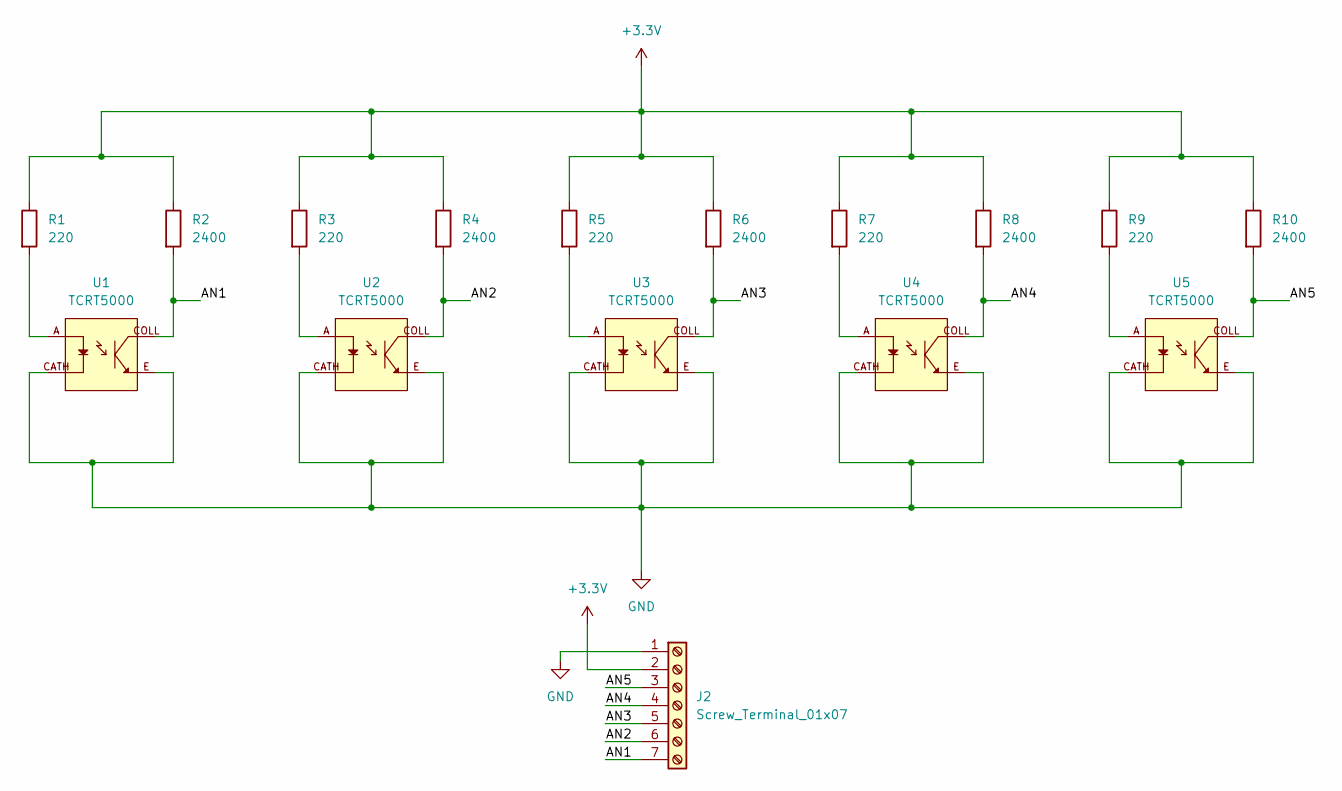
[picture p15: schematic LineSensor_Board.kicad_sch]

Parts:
J2: Screw_Terminal_01x07; PinHeader_1x07_P2.54mm_Vertical
R1, R3, R5, R7, R9: 220; R_Axial_DIN0207_L6.3mm_D2.5mm_P7.62mm_Horizontal
R2, R4, R6, R8, R10: 2400; R_Axial_DIN0207_L6.3mm_D2.5mm_P7.62mm_Horizontal
U1, U2, U3, U4, U5: TCRT5000; OPTO_TCRT5000; PARTREV 1.7

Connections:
+3.3V: J2.2, R1.1, R2.1, R3.1, R4.1, R5.1, R6.1, R7.1, R8.1, R9.1, R10.1
/AN1: J2.7, R2.2, U1.COLL
/AN2: J2.6, R4.2, U2.COLL
/AN3: J2.5, R6.2, U3.COLL
/AN4: J2.4, R8.2, U4.COLL
/AN5: J2.3, R10.2, U5.COLL
GND: J2.1, U1.CATH, U1.E, U2.CATH, U2.E, U3.CATH, U3.E, U4.CATH, U4.E, U5.CATH, U5.E
unnamed: R1.2, U1.A
unnamed: R3.2, U2.A
unnamed: R5.2, U3.A
unnamed: R7.2, U4.A
unnamed: R9.2, U5.A

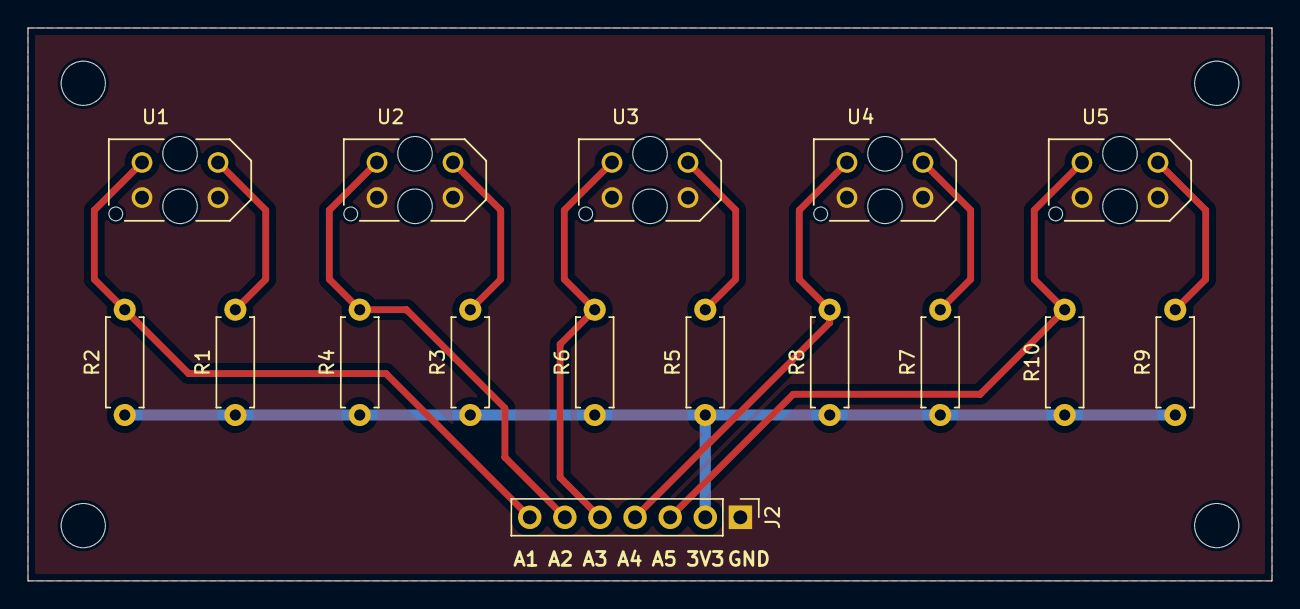
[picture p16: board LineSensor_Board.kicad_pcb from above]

Board: 2 copper layers, 90.0 x 40.0 mm, 16 parts (0 on the bottom side), 12 nets.

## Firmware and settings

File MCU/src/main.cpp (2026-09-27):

/**
 * @file main.cpp
 * @brief Main entry point and orchestrator for the ESP32 AMR firmware.
 *
 * This file contains the FreeRTOS task definitions, global state management,
 * and hardware initialization. It acts as the central coordinator for all
 * decoupled library modules.
 */
#include <cJSON.h>
#include <esp_log.h>
#include <esp_timer.h>
#include <freertos/FreeRTOS.h>
#include <freertos/task.h>
#include <lwip/sockets.h>
#include <nvs.h>
#include <nvs_flash.h>

#include "../include/main.hpp"
#include "../include/motion_task.hpp"
#include "../include/shared_state.hpp"
#include "../include/telemetry_task.hpp"

#include "../lib/adc_dma/adc_dma.hpp"
#include "../lib/loadcell_hx711/loadcell_hx711.hpp"
#include "../lib/tb6612_encoder/tb6612_encoder.hpp"
#include "../lib/velocity_pid/velocity_pid.hpp"
#include "../lib/wifi_manager/wifi_manager.hpp"

static const char *TAG = "ORCHESTRATOR";

/**
 * ============================================================================
 * \todo 3-SEGMENT GAIN SCHEDULING & PID PROFILE PLAN
 * ============================================================================
 * \par Goal:
 * Change 3 package of PID parameter for diferrents road segments

 * ============================================================================
 */

// Global Shared State
SharedRobotState robot_state = {
    .spinlock = portMUX_INITIALIZER_UNLOCKED,
    .adc_raw = {0},
    .encoder_left = 0,
    .encoder_right = 0,
    .pwm_left = 0.0f,
    .pwm_right = 0.0f,
    .target_rpm_left = 0.0f,
    .target_rpm_right = 0.0f,
    .actual_rpm_left = 0.0f,
    .actual_rpm_right = 0.0f,
    .manual_cmd_l = 0.0f,
    .manual_cmd_r = 0.0f,
    .current_e2 = 0.0f,
    .loadcell_weight = 0.0f,
    .line_calib = {.x_max = {4095, 4095, 4095, 4095, 4095},
                   .x_min = {5, 0, 0, 23, 21},
                   .y_max = 1000,
                   .y_min = 0,
                   .line_coe_1 = 1.229f,  // 1.0
                   .line_coe_2 = 1.272f}, // 0/0
    .physical_config = {.wheel_base_mm = DEFAULT_PHYS_WHEEL_BASE_MM,
                        .wheel_radius_mm = DEFAULT_PHYS_WHEEL_RADIUS_MM,
                        .sensor_distance_mm = DEFAULT_PHYS_SENSOR_DISTANCE_MM,
                        .v_ref = 200.0f, // 200 mm/s base forward velocity
                        .v_ref_turn = 500.0f,
                        .kp = DEFAULT_KP,
                        .kd = DEFAULT_KD,
                        .pid_tau = DEFAULT_PID_TAU,
                        .kp_load1 = DEFAULT_KP_LOAD1,
                        .kd_load1 = DEFAULT_KD_LOAD1,
                        .pid_tau_load1 = DEFAULT_PID_TAU_LOAD1,
                        .kp_load2 = DEFAULT_KP_LOAD2,
                        .kd_load2 = DEFAULT_KD_LOAD2,
                        .pid_tau_load2 = DEFAULT_PID_TAU_LOAD2,
                        .sensor_weight_04 = DEFAULT_SENSOR_WEIGHT_04,
                        .sensor_weight_13 = DEFAULT_SENSOR_WEIGHT_13,
                        .kp_l = DEFAULT_KP_L,
                        .ki_l = DEFAULT_KI_L,
                        .kd_l = DEFAULT_KD_L,
                        .kp_r = DEFAULT_KP_R,
                        .ki_r = DEFAULT_KI_R,
                        .kd_r = DEFAULT_KD_R},
    .track_config = {.encoder_ppr = 341.2f,
                     .turn_phase1_outer_rpm = 50.0f,
                     .turn_phase1_inner_rpm = 0.0f,
                     .turn_phase1_timeout_ticks = 8, // 6 ticks * 50ms = 400ms
                     .loadcell_type1_min = 800.0f,
                     .loadcell_type1_max = 1200.0f,
                     .loadcell_type2_min = 1800.0f,
                     .loadcell_type2_max = 2200.0f,
                     .fuzzy_mode = DEFAULT_FUZZY_MODE,
                     .blind_seg1_rpm_l = DEFAULT_BLIND_SEG1_RPM_L,
                     .blind_seg1_rpm_r = DEFAULT_BLIND_SEG1_RPM_R,
                     .blind_seg1_pulses_l = DEFAULT_BLIND_SEG1_PULSES_L,
                     .blind_seg1_pulses_r = DEFAULT_BLIND_SEG1_PULSES_R,
                     .blind_seg2_rpm_l = DEFAULT_BLIND_SEG2_RPM_L,
                     .blind_seg2_rpm_r = DEFAULT_BLIND_SEG2_RPM_R,
                     .blind_seg2_pulses_l = DEFAULT_BLIND_SEG2_PULSES_L,
                     .blind_seg2_pulses_r = DEFAULT_BLIND_SEG2_PULSES_R,
                     .blind_seg3_rpm_l = DEFAULT_BLIND_SEG3_RPM_L,
                     .blind_seg3_rpm_r = DEFAULT_BLIND_SEG3_RPM_R,
                     .pickup_stop_pulses = 10800,
                     .pickup_decel_pulses = 10000,
                     .finish_stop_pulses = 10000,
                     .finish_decel_pulses = 10000,
                     .decel_ratio = 0.65f,
                     .finish_decel_ratio = 0.40f},
    .system_running = false,
    .soft_stop_request = false,
    .test_mode_active = false,
    .test_target_rpm_l = 0.0f,
    .test_target_rpm_r = 0.0f};

// Global Drivers (Workers)
wifi_manager::WifiManager wifi;
EspAdcDmaDriver adc_driver;
Tb6612Encoder motor_left;
Tb6612Encoder motor_right;
VelocityPid pid_left;
VelocityPid pid_right;
LoadcellHX711 loadcell(PIN_LOADCELL_DT, PIN_LOADCELL_SCK);

/**
 * @brief ADC DMA Polling Task.
 *
 * Continuously polls the ADC DMA buffer and updates the global state safely.
 * This runs on Core 1 with very high priority (6) to prevent buffer overflows.
 *
 * @param pvParameters Pointer to the global SharedRobotState.
 */
void adc_task(void *pvParameters) {
  SharedRobotState *state = static_cast<SharedRobotState *>(pvParameters);
  ESP_LOGI(TAG, "ADC Task Started");

  while (true) {
    adc_driver.process_dma_events(portMAX_DELAY);

    adc_sensor_data_t adc_data;
    adc_driver.read_sensor_data(&adc_data);

    portENTER_CRITICAL(&state->spinlock);
    for (int i = 0; i < ROBOT_NUM_SENSORS; i++) {
      state->adc_raw[i] = adc_data.raw[i];
    }
    portEXIT_CRITICAL(&state->spinlock);
  }
}

/**
 * @brief HX711 Loadcell Task.
 *
 * Polls the HX711 sensor for weight data at a defined interval and updates the
 * global state. Runs on Core 1 with medium priority (3).
 *
 * @param pvParameters Pointer to the global SharedRobotState.
 */
void loadcell_task(void *pvParameters) {
  SharedRobotState *state = static_cast<SharedRobotState *>(pvParameters);
  ESP_LOGI(TAG, "Loadcell Task Started");

  while (true) {
    float weight = loadcell.get_units(1);

    portENTER_CRITICAL(&state->spinlock);
    state->loadcell_weight = weight;
    portEXIT_CRITICAL(&state->spinlock);

    vTaskDelay(pdMS_TO_TICKS(50));
  }
}

/**
 * @brief Wi-Fi Toggle Task.
 *
 * Monitors a physical switch to toggle Wi-Fi connection on/off dynamically.
 * Runs on Core 1 with low priority (2).
 *
 * @param pvParameters Not used.
 */
void wifi_toggle_task(void *pvParameters) {
  gpio_config_t io_conf = {};
  io_conf.pin_bit_mask = (1ULL << PIN_WIFI_SWITCH);
  io_conf.mode = GPIO_MODE_INPUT;
  io_conf.pull_up_en = GPIO_PULLUP_ENABLE;
  io_conf.pull_down_en = GPIO_PULLDOWN_DISABLE;
  io_conf.intr_type = GPIO_INTR_DISABLE;
  gpio_config(&io_conf);

  bool wifi_is_running =
      true; // Wi-Fi is already started in app_main by wifi.init()

  while (true) {
    int switch_state = gpio_get_level(PIN_WIFI_SWITCH);

    // Switch connected to GND -> state 0 -> turn ON Wi-Fi
    if (switch_state == 0 && !wifi_is_running) {
      ESP_LOGI(TAG, "Switch ON: Starting Wi-Fi...");
      wifi.start();
      wifi_is_running = true;
    }
    // Switch disconnected -> state 1 (pull-up) -> turn OFF Wi-Fi
    else if (switch_state == 1 && wifi_is_running) {
      ESP_LOGI(TAG, "Switch OFF: Stopping Wi-Fi...");
      wifi.stop();
      wifi_is_running = false;
    }

    vTaskDelay(pdMS_TO_TICKS(200));
  }
}

struct NvsPidData {
  float kp, kd, pid_tau;
  float kp_load1, kd_load1, pid_tau_load1;
  float kp_load2, kd_load2, pid_tau_load2;
  float sensor_weight_04, sensor_weight_13;
  float kp_l, ki_l, kd_l;
  float kp_r, ki_r, kd_r;
  float v_ref;
  float v_ref_turn;
};

struct NvsBlindData {
  bool fuzzy_mode;
  float blind_seg1_rpm_l;
  float blind_seg1_rpm_r;
  int64_t blind_seg1_pulses_l;
  int64_t blind_seg1_pulses_r;
  float blind_seg2_rpm_l;
  float blind_seg2_rpm_r;
  int64_t blind_seg2_pulses_l;
  int64_t blind_seg2_pulses_r;
  float blind_seg3_rpm_l;
  float blind_seg3_rpm_r;
};

/**
 * @brief Loads PID and Blind run parameters from NVS flash memory.
 *
 * @param state Reference to the global SharedRobotState where config will be
 * stored.
 */
void load_nvs_params(SharedRobotState &state) {
  nvs_handle_t my_handle;
  esp_err_t err = nvs_open("storage", NVS_READONLY, &my_handle);
  if (err != ESP_OK) {
    ESP_LOGW(TAG, "Error (%s) opening NVS handle! Using defaults.",
             esp_err_to_name(err));
    return;
  }

  NvsPidData pid_data;
  size_t required_size = sizeof(NvsPidData);
  err = nvs_get_blob(my_handle, "pid_cfg", &pid_data, &required_size);
  if (err == ESP_OK) {
    state.physical_config.kp = pid_data.kp;
    state.physical_config.kd = pid_data.kd;
    state.physical_config.pid_tau = pid_data.pid_tau;
    state.physical_config.kp_load1 = pid_data.kp_load1;
    state.physical_config.kd_load1 = pid_data.kd_load1;
    state.physical_config.pid_tau_load1 = pid_data.pid_tau_load1;
    state.physical_config.kp_load2 = pid_data.kp_load2;
    state.physical_config.kd_load2 = pid_data.kd_load2;
    state.physical_config.pid_tau_load2 = pid_data.pid_tau_load2;
    state.physical_config.sensor_weight_04 = pid_data.sensor_weight_04;
    state.physical_config.sensor_weight_13 = pid_data.sensor_weight_13;
    state.physical_config.kp_l = pid_data.kp_l;
    state.physical_config.ki_l = pid_data.ki_l;
    state.physical_config.kd_l = pid_data.kd_l;
    state.physical_config.kp_r = pid_data.kp_r;
    state.physical_config.ki_r = pid_data.ki_r;
    state.physical_config.kd_r = pid_data.kd_r;
    state.physical_config.v_ref = pid_data.v_ref;
    state.physical_config.v_ref_turn = pid_data.v_ref_turn;
    ESP_LOGI(TAG, "Loaded PID params from NVS successfully.");
  } else {
    ESP_LOGW(TAG, "Failed to load PID params from NVS (using defaults).");
  }

  NvsBlindData blind_data;
  size_t blind_size = sizeof(NvsBlindData);
  err = nvs_get_blob(my_handle, "blind_cfg", &blind_data, &blind_size);
  if (err == ESP_OK) {
    state.track_config.fuzzy_mode = blind_data.fuzzy_mode;
    state.track_config.blind_seg1_rpm_l = blind_data.blind_seg1_rpm_l;
    state.track_config.blind_seg1_rpm_r = blind_data.blind_seg1_rpm_r;
    state.track_config.blind_seg1_pulses_l = blind_data.blind_seg1_pulses_l;
    state.track_config.blind_seg1_pulses_r = blind_data.blind_seg1_pulses_r;
    state.track_config.blind_seg2_rpm_l = blind_data.blind_seg2_rpm_l;
    state.track_config.blind_seg2_rpm_r = blind_data.blind_seg2_rpm_r;
    state.track_config.blind_seg2_pulses_l = blind_data.blind_seg2_pulses_l;
    state.track_config.blind_seg2_pulses_r = blind_data.blind_seg2_pulses_r;
    state.track_config.blind_seg3_rpm_l = blind_data.blind_seg3_rpm_l;
    state.track_config.blind_seg3_rpm_r = blind_data.blind_seg3_rpm_r;
    ESP_LOGI(TAG, "Loaded Blind Run / Fuzzy params from NVS successfully.");
  } else {
    ESP_LOGW(TAG, "Failed to load Blind Run params from NVS (using defaults).");
  }

  nvs_close(my_handle);
}

/**
 * @brief Saves the current PID and physical parameters to NVS flash memory.
 *
 * @param state Reference to the global SharedRobotState containing the config.
 */
void save_nvs_params(const SharedRobotState &state) {
  nvs_handle_t my_handle;
  esp_err_t err = nvs_open("storage", NVS_READWRITE, &my_handle);
  if (err != ESP_OK) {
    ESP_LOGE(TAG, "Error (%s) opening NVS handle to save!",
             esp_err_to_name(err));
    return;
  }

  NvsPidData pid_data = {
      .kp = state.physical_config.kp,
      .kd = state.physical_config.kd,
      .pid_tau = state.physical_config.pid_tau,
      .kp_load1 = state.physical_config.kp_load1,
      .kd_load1 = state.physical_config.kd_load1,
      .pid_tau_load1 = state.physical_config.pid_tau_load1,
      .kp_load2 = state.physical_config.kp_load2,
      .kd_load2 = state.physical_config.kd_load2,
      .pid_tau_load2 = state.physical_config.pid_tau_load2,
      .sensor_weight_04 = state.physical_config.sensor_weight_04,
      .sensor_weight_13 = state.physical_config.sensor_weight_13,
      .kp_l = state.physical_config.kp_l,
      .ki_l = state.physical_config.ki_l,
      .kd_l = state.physical_config.kd_l,
      .kp_r = state.physical_config.kp_r,
      .ki_r = state.physical_config.ki_r,
      .kd_r = state.physical_config.kd_r,
      .v_ref = state.physical_config.v_ref,
      .v_ref_turn = state.physical_config.v_ref_turn};

  err = nvs_set_blob(my_handle, "pid_cfg", &pid_data, sizeof(NvsPidData));
  if (err == ESP_OK) {
    ESP_LOGI(TAG, "Saved PID params to NVS blob.");
  }

  NvsBlindData blind_data = {
      .fuzzy_mode = state.track_config.fuzzy_mode,
      .blind_seg1_rpm_l = state.track_config.blind_seg1_rpm_l,
      .blind_seg1_rpm_r = state.track_config.blind_seg1_rpm_r,
      .blind_seg1_pulses_l = state.track_config.blind_seg1_pulses_l,
      .blind_seg1_pulses_r = state.track_config.blind_seg1_pulses_r,
      .blind_seg2_rpm_l = state.track_config.blind_seg2_rpm_l,
      .blind_seg2_rpm_r = state.track_config.blind_seg2_rpm_r,
      .blind_seg2_pulses_l = state.track_config.blind_seg2_pulses_l,
      .blind_seg2_pulses_r = state.track_config.blind_seg2_pulses_r,
      .blind_seg3_rpm_l = state.track_config.blind_seg3_rpm_l,
      .blind_seg3_rpm_r = state.track_config.blind_seg3_rpm_r};

  err = nvs_set_blob(my_handle, "blind_cfg", &blind_data, sizeof(NvsBlindData));
  if (err == ESP_OK) {
    ESP_LOGI(TAG, "Saved Blind Run params to NVS blob.");
  }

  err = nvs_commit(my_handle);
  if (err == ESP_OK) {
    ESP_LOGI(TAG, "NVS commit successful.");
  }
  nvs_close(my_handle);
}
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
extern "C" void app_main() {
  ESP_LOGI(TAG, "Initializing Orchestrator...");

#if USE_LAPTOP_HOTSPOT
  wifi_manager::WifiConfig wifi_cfg(wifi_manager::WifiMode::MODE_STA,
                                    WIFI_HOTSPOT_SSID, WIFI_HOTSPOT_PASS);
#else
  wifi_manager::WifiConfig wifi_cfg(wifi_manager::WifiMode::MODE_STA,
                                    WIFI_ROUTER_SSID, WIFI_ROUTER_PASS);
#endif
  ESP_ERROR_CHECK(wifi.init(wifi_cfg));
  // wifi.start(); // Handled dynamically by wifi_toggle_task

  // Load PID parameters from NVS
  load_nvs_params(robot_state);

  adc_dma_config_t adc_cfg = {};
  adc_cfg.sample_freq_hz = 20000;
  adc_cfg.dma_frame_size = 256;
  adc_cfg.channel_map[SENSOR_01] = PIN_ADC_SENSOR_02; // Swapped 1 and 2
  adc_cfg.channel_map[SENSOR_02] = PIN_ADC_SENSOR_01; // Swapped 1 and 2
  adc_cfg.channel_map[SENSOR_03] = PIN_ADC_SENSOR_04; // Swapped 3 and 4
  adc_cfg.channel_map[SENSOR_04] = PIN_ADC_SENSOR_03; // Swapped 3 and 4
  adc_cfg.channel_map[SENSOR_05] = PIN_ADC_SENSOR_05;
  ESP_ERROR_CHECK(adc_driver.init(adc_cfg));
  ESP_ERROR_CHECK(adc_driver.start());

  tb6612_config_t mleft_cfg = {.pwm_gpio = PIN_MOTOR_L_PWM,
                               .in1_gpio = PIN_MOTOR_L_IN1,
                               .in2_gpio = PIN_MOTOR_L_IN2,
                               .enc_a_gpio = PIN_ENC_L_A,
                               .enc_b_gpio = PIN_ENC_L_B,
                               .pwm_freq_hz = 1000,
                               .encoder_ppr = PHYS_ENCODER_PPR,
                               .pcnt_high_limit = 30000,
                               .pcnt_low_limit = -30000};
  ESP_ERROR_CHECK(motor_left.init(mleft_cfg));

  tb6612_config_t mright_cfg = {.pwm_gpio = PIN_MOTOR_R_PWM,
                                .in1_gpio = PIN_MOTOR_R_IN1,
                                .in2_gpio = PIN_MOTOR_R_IN2,
                                .enc_a_gpio = PIN_ENC_R_A,
                                .enc_b_gpio = PIN_ENC_R_B,
                                .pwm_freq_hz = 1000,
                                .encoder_ppr = PHYS_ENCODER_PPR,
                                .pcnt_high_limit = 30000,
                                .pcnt_low_limit = -30000};
  ESP_ERROR_CHECK(motor_right.init(mright_cfg));

  velocity_pid_config_t pid_cfg_l = {
      .kp = robot_state.physical_config.kp_l,
      .ki = robot_state.physical_config.ki_l,
      .kd = robot_state.physical_config.kd_l,
      .out_max = 85.0f,      // Maximum PWM duty cycle limit is 85%
      .out_min = 0.0f,       // Enforce >= 0 for safety against reverse pulses
      .integral_max = 85.0f, // Corresponding Integral Anti-Windup limit
      .max_accel_units_s2 = 5000.0f};
  velocity_pid_config_t pid_cfg_r = {
      .kp = robot_state.physical_config.kp_r,
      .ki = robot_state.physical_config.ki_r,
      .kd = robot_state.physical_config.kd_r,
      .out_max = 85.0f,
      .out_min = 0.0f, // Enforce >= 0 for safety against reverse pulses
      .integral_max = 85.0f,
      .max_accel_units_s2 = 5000.0f};
  pid_left.init(pid_cfg_l);
  pid_right.init(pid_cfg_r);

  if (loadcell.begin(128)) {
    ESP_LOGI(TAG, "Waiting for HX711 to stabilize...");
    // 1. Wait for physical strain gauge to settle after power up
    vTaskDelay(pdMS_TO_TICKS(1000));

    // 2. Discard first few unstable readings
    loadcell.read_average(3);

    // 3. Tare with higher sample count for better zeroing accuracy (20 samples
    // = ~2 seconds)
    ESP_LOGI(TAG, "Taring loadcell...");
    loadcell.tare(20);

    // New scale factor based on the average:
    // (184.5 * 2280) / 1 = 420,660 raw/kg
    // (371.5 * 2280) / 2 = 423,510 raw/kg
    // (556.5 * 2280) / 3 = 422,940 raw/kg
    // Average = 422,370 raw / 1 kg.
    // To output in grams (1kg = 1000g), Scale = 422,370 / 1000 = 422.37.
    // Minus sign (-) to invert negative values to positive.
    loadcell.set_scale(-422.37f);
    ESP_LOGI(TAG, "Loadcell ready.");
  }

  // Orchestrate tasks with explicit Core Pinning and Priorities
  xTaskCreatePinnedToCore(adc_task, "ADC_Task", 4096, &robot_state, 6, nullptr,
                          1);
  xTaskCreatePinnedToCore(loadcell_task, "Load_Task", 4096, &robot_state, 3,
                          nullptr, 1);
  xTaskCreatePinnedToCore(motion_task_routine, "Motion_Task", 4096,
                          &robot_state, 5, nullptr, 1);
  xTaskCreatePinnedToCore(telemetry_task_routine, "Tele_Task", 4096,
                          &robot_state, 2, nullptr, 0);
  xTaskCreatePinnedToCore(wifi_toggle_task, "Wifi_Toggle", 2048, nullptr, 2,
                          nullptr, 1);
  xTaskCreatePinnedToCore(udp_receiver_task, "UDP_Recv", 4096, &robot_state, 1,
                          nullptr, 0);

  ESP_LOGI(TAG, "Tasks deployed. Yielding app_main.");
}

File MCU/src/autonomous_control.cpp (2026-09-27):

#include "../include/autonomous_control.hpp"
#include <cmath>

MotionOutput AutonomousControl::compute(const StateSnapshot &state, float dt_s,
                                        uint32_t loop_counter) {
  // 1. Odometry calculation
  float ppr = state.track_config.encoder_ppr;
  if (ppr < 1.0f)
    ppr = 341.2f; // Fallback safety

  // Calculate delta pulses
  int64_t d_pulse_l = state.encoder_l - _prev_encoder_l;
  int64_t d_pulse_r = state.encoder_r - _prev_encoder_r;
  _prev_encoder_l = state.encoder_l;
  _prev_encoder_r = state.encoder_r;

  // Convert to distance: distance = (d_pulses / PPR) * (2 * PI * radius)
  float d_dist_l =
      (static_cast<float>(d_pulse_l) / ppr) *
      (2.0f * static_cast<float>(M_PI) * state.physical_config.wheel_radius_mm);
  float d_dist_r =
      (static_cast<float>(d_pulse_r) / ppr) *
      (2.0f * static_cast<float>(M_PI) * state.physical_config.wheel_radius_mm);

  _total_displacement_mm += (std::abs(d_dist_l) + std::abs(d_dist_r)) / 2.0f;
  float current_displacement =
      _total_displacement_mm - _reference_displacement_mm;

  // 2. State Machine execution
  if (loop_counter % PID_EXEC_DECIMATION == 0) {
    uint32_t masked_adc[ROBOT_NUM_SENSORS];
    for (int i = 0; i < ROBOT_NUM_SENSORS; i++) {
      masked_adc[i] = state.adc_raw[i];
    }

    if (_current_state == TrackState::DELIVERING_TYPE_1) {
      masked_adc[3] = 0;
      masked_adc[4] = 0;
    } else if (_current_state == TrackState::DELIVERING_TYPE_2) {
      masked_adc[0] = 0;
      masked_adc[1] = 0;
    }

    bool in_curve = false;
    if (_current_state == TrackState::MOVING_TO_PICKUP && _is_carrying_package) {
      int64_t d_pulse_pickup_l = state.encoder_l - _post_pickup_enc_l;
      int64_t d_pulse_pickup_r = state.encoder_r - _post_pickup_enc_r;
      in_curve =
          (d_pulse_pickup_l >= 2700 && (d_pulse_pickup_l - 2700) < 10000) ||
          (d_pulse_pickup_r >= 2700 && (d_pulse_pickup_r - 2700) < 7000);
    }

    float e2 = _line_tracker.compute_e2(masked_adc, state.line_calib,
                                        state.physical_config);
    _last_e2 = e2;

    switch (_current_state) {
    case TrackState::MOVING_TO_PICKUP: {
      // 1. End of line detection (5 sensors white) OR Line lost recovery
      if (state.adc_raw[0] < 2500 && state.adc_raw[1] < 2500 &&
          state.adc_raw[2] < 2500 && state.adc_raw[3] < 2500 &&
          state.adc_raw[4] < 2500) {

        int64_t post_turn_l = state.encoder_l - _post_turn_encoder_l;
        int64_t post_turn_r = state.encoder_r - _post_turn_encoder_r;
        int64_t finish_thresh = state.track_config.finish_stop_pulses > 0
                                    ? state.track_config.finish_stop_pulses
                                    : 10000;
        if (_has_turned && post_turn_l >= finish_thresh &&
            post_turn_r >= finish_thresh) {
          // Reached the end of the track
          _current_state = TrackState::FINISHED;
          _last_target_rpm_l = 0.0f;
          _last_target_rpm_r = 0.0f;
          break;
        } else {
          // Lost line, perform recovery based on last known error (e2)
          if (e2 > 0.0f) {
            // Line was to the right, car veered left. Steer Right.
            _last_target_rpm_l = state.track_config.turn_phase1_outer_rpm;
            _last_target_rpm_r = state.track_config.turn_phase1_inner_rpm;
          } else {
            // Line was to the left, car veered right. Steer Left.
            _last_target_rpm_l = state.track_config.turn_phase1_inner_rpm;
            _last_target_rpm_r = state.track_config.turn_phase1_outer_rpm;
          }
        }
        break; // Skip normal PID
      }

      // 1.5. Fallback stop at pickup point
      int64_t pickup_stop = state.track_config.pickup_stop_pulses > 0
                                ? state.track_config.pickup_stop_pulses
                                : 10800;
      if (!_is_carrying_package && state.encoder_l >= pickup_stop &&
          state.encoder_r >= pickup_stop) {
        _current_state = TrackState::WAITING_FOR_PACKAGE;
        _last_target_rpm_l = 0.0f;
        _last_target_rpm_r = 0.0f;
        _line_tracker.reset();
        break;
      }

      // 2. Cargo validation if carrying
      if (_is_carrying_package) {
        float weight = state.loadcell_weight;
        bool weight_valid = false;

        if (_cargo_type == 1 &&
            weight >= state.track_config.loadcell_type1_min &&
            weight <= state.track_config.loadcell_type1_max) {
          weight_valid = true;
        } else if (_cargo_type == 2 &&
                   weight >= state.track_config.loadcell_type2_min &&
                   weight <= state.track_config.loadcell_type2_max) {
          weight_valid = true;
        }

        if (!weight_valid) {
          _recovery_ticks++;
          if (_recovery_ticks >= 6) { // ~300ms continuous invalid load (filter vibration)
            _current_state = TrackState::FINISHED; // Stop permanently
            _last_target_rpm_l = 0.0f;
            _last_target_rpm_r = 0.0f;
            break;
          }
        } else {
          _recovery_ticks = 0; // Reset debounce if load bounces back
        }
      }

      // 3. T-Junction (Pickup point): Center 3 black, outer 2 white
      if (!_is_carrying_package && state.adc_raw[0] < 2000 &&
          state.adc_raw[1] > 2000 && state.adc_raw[2] > 2000 &&
          state.adc_raw[3] > 2000 && state.adc_raw[4] < 2000) {
        _current_state = TrackState::WAITING_FOR_PACKAGE;
        _last_target_rpm_l = 0.0f;
        _last_target_rpm_r = 0.0f;
        _line_tracker.reset();
        break;
      }

      // 4. Y-Junction (Turn point): Center 3 black, outer 2 white
      if (_is_carrying_package && current_displacement > 200.0f) {
        if (state.adc_raw[0] < 2000 && state.adc_raw[1] > 2000 &&
            state.adc_raw[2] > 2000 && state.adc_raw[3] > 2000 &&
            state.adc_raw[4] < 2000) {
          if (_cargo_type == 1) {
            _current_state = TrackState::DELIVERING_TYPE_1;
          } else if (_cargo_type == 2) {
            _current_state = TrackState::DELIVERING_TYPE_2;
          }
          _recovery_ticks = 0;
          break;
        }
      }

      // Use physical config (updated via UDP 'tune' and saved to NVS)
      RobotPhysicalConfig dyn_config = state.physical_config;

      // Default: Use Set 1 (kp, kd, pid_tau) for all normal segments
      dyn_config.kp = state.physical_config.kp;
      dyn_config.kd = state.physical_config.kd;
      dyn_config.pid_tau = state.physical_config.pid_tau;
      dyn_config.v_ref = state.physical_config.v_ref;

      if (_is_carrying_package) {
        int64_t d_pulse_pickup_l = state.encoder_l - _post_pickup_enc_l;
        int64_t d_pulse_pickup_r = state.encoder_r - _post_pickup_enc_r;

        bool after_curve =
            !in_curve && (d_pulse_pickup_l >= 2700 || d_pulse_pickup_r >= 2700);
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

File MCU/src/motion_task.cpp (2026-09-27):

/**
 * @file motion_task.cpp
 * @brief FreeRTOS task for motion control, sensor reading, and PID execution.
 *
 * This module integrates the encoder readings, line sensor data, and executes
 * the velocity and steering PID controllers to drive the motors.
 */
#include "../include/motion_task.hpp"
#include "../include/autonomous_control.hpp"
#include "../include/main.hpp"
#include "../include/manual_control.hpp"
#include "../include/motion_strategy.hpp"
#include "../include/shared_state.hpp"
#include "../lib/tb6612_encoder/tb6612_encoder.hpp"
#include "../lib/velocity_pid/velocity_pid.hpp"
#include <driver/gpio.h>
#include <esp_timer.h>

#if CONTROL_MODE == 1
static ManualControl motion_controller;
#else
static AutonomousControl motion_controller;
#endif

extern Tb6612Encoder motor_left;
extern Tb6612Encoder motor_right;
extern VelocityPid pid_left;
extern VelocityPid pid_right;

/**
 * @brief Main motion control task routine.
 *
 * Runs at a strict 100Hz frequency. Reads encoders, calculates instant RPM,
 * applies EMA filtering for quantization noise reduction, runs Line Tracking
 * PID at 20Hz, and updates Motor Velocity PIDs.
 *
 * @param pvParameters Pointer to the global SharedRobotState.
 */
void motion_task_routine(void *pvParameters) {
  SharedRobotState *state = static_cast<SharedRobotState *>(pvParameters);
  
  float target_rpm_l = 0.0f;
  float target_rpm_r = 0.0f;
  float current_e2 = 0.0f;

  bool prev_system_running = false;

  TickType_t last_wake_time = xTaskGetTickCount();
  const TickType_t freq_ticks = pdMS_TO_TICKS(10); // 100Hz

  int64_t last_time_us = esp_timer_get_time();
  int64_t last_pulse_l = 0;
  int64_t last_pulse_r = 0;
  int64_t enc_offset_l = 0;
  int64_t enc_offset_r = 0;

  motor_left.get_pulse_count(last_pulse_l);
  motor_right.get_pulse_count(last_pulse_r);

  uint32_t loop_counter = 0;
  uint32_t stop_hold_ticks = 0;

  gpio_config_t io_conf = {};
  io_conf.pin_bit_mask = (1ULL << GPIO_NUM_0);
  io_conf.mode = GPIO_MODE_INPUT;
  io_conf.pull_up_en = GPIO_PULLUP_ENABLE;
  io_conf.pull_down_en = GPIO_PULLDOWN_DISABLE;
  io_conf.intr_type = GPIO_INTR_DISABLE;
  gpio_config(&io_conf);

  while (true) {
    int64_t current_pulse_l = 0;
    int64_t current_pulse_r = 0;
    motor_left.get_pulse_count(current_pulse_l);
    motor_right.get_pulse_count(current_pulse_r);

    int64_t current_time_us = esp_timer_get_time();
    int64_t delta_time_us = current_time_us - last_time_us;

    if (delta_time_us > 0) {
      float dt_s = static_cast<float>(delta_time_us) / 1000000.0f;
      float raw_rpm_l = 0.0f;
      float raw_rpm_r = 0.0f;

      motor_left.get_current_rpm(current_pulse_l, last_pulse_l, delta_time_us,
                                 raw_rpm_l);
      motor_right.get_current_rpm(current_pulse_r, last_pulse_r, delta_time_us,
                                  raw_rpm_r);

      // JGB37-520 Hardware Quadrature Scaling (x4 division)
      // Optimized: Multiplication by 0.25f is faster than division by 4.0f
      float instant_rpm_l = raw_rpm_l * 0.25f;
      float instant_rpm_r = raw_rpm_r * 0.25f;

      /**
       * @note EMA LOW-PASS FILTER FOR QUANTIZATION NOISE REDUCTION
       * At 100Hz sampling rate (10ms dt), a 1-pulse encoder difference can
       * cause an RPM jump of ~4.5 RPM due to quantization. The EMA filter
       * smooths this out. Alpha is the filter coefficient (smaller = smoother
       * but higher phase lag). 0.15 is chosen as an optimal balance for this
       * encoder's PPR.
       */
      static float filtered_rpm_l = 0.0f;
      static float filtered_rpm_r = 0.0f;
      constexpr float ALPHA =
          1.0f; // EMA filter coefficient for quantization noise

      filtered_rpm_l =
          (ALPHA * instant_rpm_l) + ((1.0f - ALPHA) * filtered_rpm_l);
      filtered_rpm_r =
          (ALPHA * instant_rpm_r) + ((1.0f - ALPHA) * filtered_rpm_r);

      float rpm_l = filtered_rpm_l;
      float rpm_r = filtered_rpm_r;

      bool is_test_mode = false;
      float test_target_rpm_l_val = 0.0f;
      float test_target_rpm_r_val = 0.0f;
      
      StateSnapshot snap;
      portENTER_CRITICAL(&state->spinlock);
      for (int i = 0; i < ROBOT_NUM_SENSORS; i++) {
        snap.adc_raw[i] = state->adc_raw[i];
      }
      snap.line_calib = state->line_calib;
      snap.physical_config = state->physical_config;
      snap.manual_cmd_l = state->manual_cmd_l;
      snap.manual_cmd_r = state->manual_cmd_r;
      snap.loadcell_weight = state->loadcell_weight;
      snap.track_config = state->track_config;
      
      is_test_mode = state->test_mode_active;
      test_target_rpm_l_val = state->test_target_rpm_l;
      test_target_rpm_r_val = state->test_target_rpm_r;
      portEXIT_CRITICAL(&state->spinlock);

      // Pass the *raw* un-decimated pulses so we get accurate displacement
      int64_t relative_pulse_l = current_pulse_l - enc_offset_l;
      int64_t relative_pulse_r = current_pulse_r - enc_offset_r;
      snap.encoder_l = relative_pulse_l;
      snap.encoder_r = relative_pulse_r;

      // Compute strategy (Manual or Autonomous) - ONLY ONCE
      MotionOutput m_out;
      if (is_test_mode) {
        m_out.target_rpm_left = test_target_rpm_l_val;
        m_out.target_rpm_right = test_target_rpm_r_val;
        m_out.current_e2 = 0.0f;
        m_out.is_finished = false;
      } else {
        m_out = motion_controller.compute(snap, dt_s, loop_counter);
      }
      target_rpm_l = m_out.target_rpm_left;
      target_rpm_r = m_out.target_rpm_right;
      current_e2 = m_out.current_e2;

      // #if CONTROL_MODE == 1
      //       // DEBUG MODE: Bypass PID, treat manual target as raw PWM duty
      //       cycle (-100 to 100) float duty_l = target_rpm_l; float duty_r =
      //       target_rpm_r;
      // #else

      bool current_system_running = false;
      bool current_soft_stop_req = false;
      portENTER_CRITICAL(&state->spinlock);
      current_system_running = state->system_running;
      current_soft_stop_req = state->soft_stop_request;
      portEXIT_CRITICAL(&state->spinlock);

      // Auto-stop logic when reaching the end of the track
      if (m_out.is_finished && current_system_running && !current_soft_stop_req) {
        portENTER_CRITICAL(&state->spinlock);
        state->soft_stop_request = true;
        current_soft_stop_req = true;
        portEXIT_CRITICAL(&state->spinlock);
      }
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

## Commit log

2026-06-22 hardware: PCB_demo complete
    [main_controller.kicad_pcb, main_controller.kicad_sch]
2026-06-25 chore(setup): init stm32 workspace
2026-06-27 refactor(mcu): migrate firmware project from STM32 to ESP32
2026-06-30 fix: change ESP_ERR_CHECK to return esp_err_t for more robust
    [AdcTest.cpp, MotorTest.cpp, WifiTest.cpp]
2026-06-30 feat: implement telemetry for logging data to UI, update UI for drawing ADC
2026-07-02 fix: fix telemetry message format
    [WifiTest.cpp, main.cpp, motion_task.cpp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]
2026-07-03 feat(sensor): integrate HX711 loadcell and standardize documentation
2026-07-29 bringup: line-sensor board
    [LineSensor_Board.kicad_pcb, LineSensor_Board.kicad_sch]
2026-08-07 implement: robot_state change: pin mapping
2026-08-08 Implement: update PID coefiecent on nvs flash through UI
2026-08-11 MCU: implement PID argorithm UI: change frontend for easy PID tune
2026-08-15 pid: update pid and shaping orbit, push parameters to nvs for easy calib
2026-08-18 pid: temporary 1
2026-08-23 add: 3D model, pcb layout and matlab simulation
    [4x6_Board_new.SLDPRT, 85mm_Wheel.SLDPRT, Banh_V2_65mm.SLDPRT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]
2026-08-24 save: status before sensor masking
2026-09-08 add: ADC min value observation; turn velocity
